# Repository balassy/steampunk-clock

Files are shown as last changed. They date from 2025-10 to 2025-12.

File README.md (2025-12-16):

# Steampunk Clock 🕰️

 

## Hardware 🪛

### Components 🔩

- Wemos D1 Mini microcontroller (ESP8266)
- PCF8574 I2C expander module 
- DS3231 RTC module + LIR2032 rechargable 3.6V battery
- 2× SG90 servo motors
- 2× yellow led filament strips 38mm length
- 2× 100 Ω resistors
- 4-position (rotary) switch
- Push button
- Active buzzer (12×9.5mm)
- Cables, connectors

### Wiring 🛠️

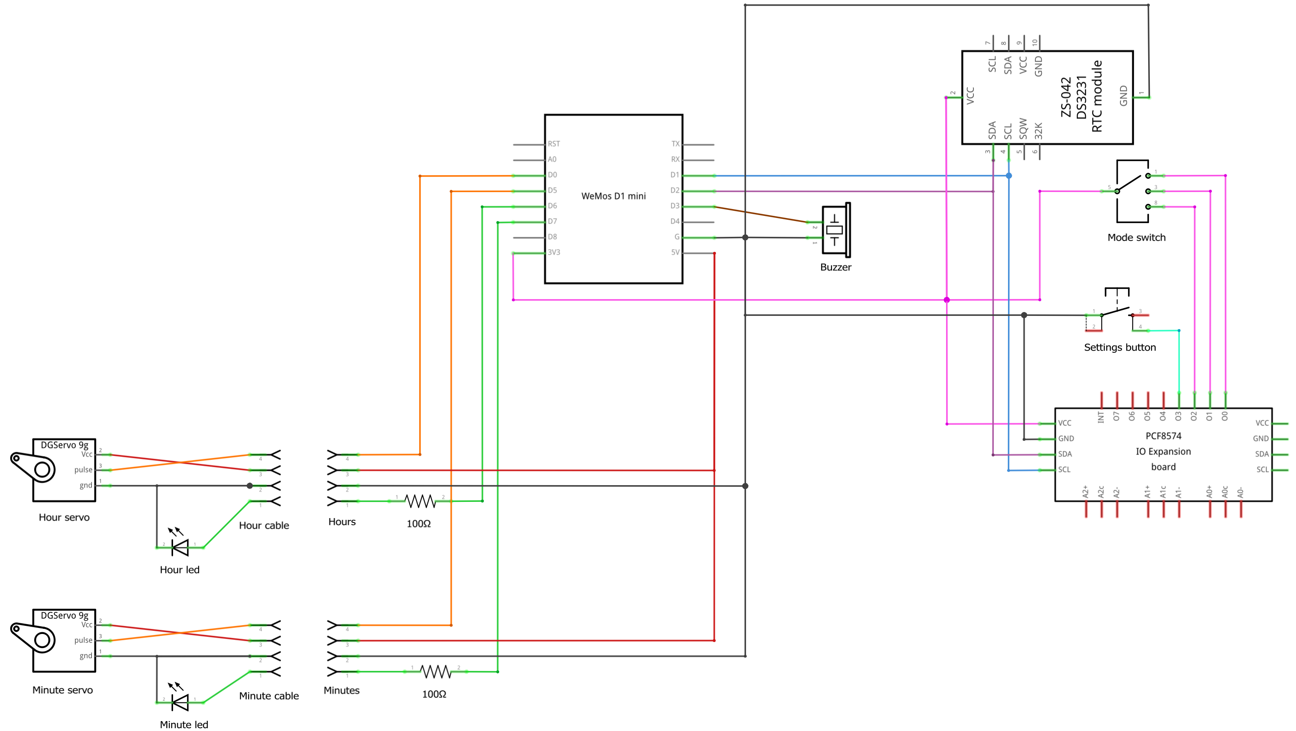
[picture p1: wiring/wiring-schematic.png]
Wiring schematic


See the details in the [wiring/steampunk-clock.fzz](./wiring/steampunk-clock.fzz) file. 

## Software 💻

### Getting Started 🚀

Install the [Arduino Maker Workshop](https://marketplace.visualstudio.com/items?itemName=TheLastOutpostWorkshop.arduino-maker-workshop) Visual Studio Code extension.

Install the following libraries:
- [Adafruit BusIO by Adafruit](https://github.com/adafruit/Adafruit_BusIO)
- [Adafruit PCF8574 by Adafruit](https://github.com/adafruit/Adafruit_PCF8574)
- [RTCLib by Adafruit](https://github.com/adafruit/RTClib)
- [WiFiManager by tzapu](https://github.com/tzapu/WiFiManager)
- [OneButton by Matthias Hertel](https://github.com/mathertel/OneButton)

The exact versions of these libraries used to create this code are visible in the [sketch.yaml](./sketch.yaml) file.

### Configuration ⚙️

Check the settings in the [config.h](./config.h) file.

**IMPORTANT FOR SECURITY!** Make sure to set a custom password in the `WIFI_AP_PASSWORD` field!

### Connecting to WiFi 📶

When the RTC module reports power loss the clock connects to a Network Time Protocol (NTP) server over the internet to get the current time.

The first time the module will create a temporary WiFi access point with the SSID and password defined in the `WIFI_AP_SSID` and `WIFI_AP_PASSWORD` values in the [config.h](./config.h) file.

Steps to connect to your local wireless network:

- Connect to this temporary access point.
- Navigate to http://192.168.4.1 in your browser.
- Select your network and enter your WiFi password.

## Acknowledgements 🙏

Thanks to Werner Rothschopf for his NTP articles:

- [NTP DST for the ESP8266](https://werner.rothschopf.net/202011_arduino_esp8266_ntp_en.htm)
- [NTP / Timezone Configuration via Webserver Interface (ESP8266, ESP32)](https://werner.rothschopf.net/202011_arduino_esp8266_ntp_en.htm)

## About the author

This project is created and maintained by [György Balássy](https://www.linkedin.com/in/balassy).

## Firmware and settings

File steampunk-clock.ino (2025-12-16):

// Platform libraries.
#include <Arduino.h>     // To add IntelliSense for platform constants.

// Third-party libraries.
#include <WiFiManager.h>      // https://github.com/tzapu/WiFiManager
#include <OneButton.h>        // https://github.com/mathertel/OneButton
#include <Adafruit_PCF8574.h> // https://github.com/adafruit/Adafruit_PCF8574
#include <Wire.h>             // I2C library

// Read configuration and secrets.
#include "config.h"

// Project classes.
#include "beep-manager.h"
#include "reboot-manager.h"
#include "ntp-manager.h"
#include "rtc-manager.h"
#include "selector-switch.h"
#include "speed-servo.h"
#include "status-led.h"

#define BUTTON_ACTIVE_LOW true

Adafruit_PCF8574 expander;
BeepManager beepManager;
NTPManager ntpManager;
SelectorSwitch selectorSwitch;
SpeedServo hourServo;
SpeedServo minuteServo;
StatusLed statusLed;
StatusLed hourLed;
StatusLed minuteLed;
RTCManager rtc;
OneButton settingsButton;

unsigned long lastClockUpdateMsec = 0;

enum Mode {
  ALL_LIGHTS_OFF = 0,
  BACKLIGHTS_ONLY,
  AMBIENT_LIGHTS_ONLY,
  ALL_LIGHTS_ON
};

void setup() {
  initSerial();
  initExpander();
  initLeds();
  initButton();
  initSwitch();
  
  if (RebootManager::isReset())
  {
    Serial.println(F("setup: Detected reset."));
  } else {
    Serial.println(F("setup: Detected power-up boot."));
  }
  RebootManager::markSetupComplete();
  
  initRTC();
  initServos();
  initBuzzer();

  Serial.println(F("setup: DONE."));
}

void loop() {
  // IMPORTANT! Do NOT use delay() in the main loop when using OneButton, as it would prevent the button from being handled!
  bool settingsButtonState = (expander.digitalRead(EXPANDER_PIN_SETTINGS_BUTTON) == LOW);
  settingsButton.tick(settingsButtonState);

  selectorSwitch.tick();

  beepManager.loop();

  // Manually detecting the number of milliseconds passed to avoid using delay() which would block button handling.
  unsigned long currentMsec = millis();
  if(currentMsec - lastClockUpdateMsec >= CLOCK_UPDATE_INTERVAL_MSEC) {
    lastClockUpdateMsec = currentMsec;
    updateClock();
  }
}

void initSerial() {
  Serial.begin(SERIAL_BAUD_RATE);
  Serial.println();
  Serial.println(F("initSerial: Initializing serial connection DONE."));
}

void initExpander() {
  Serial.println(F("initExpander: Initializing I2C expander..."));

  if (!expander.begin(0x20, &Wire)) {
    Serial.println(F("initExpander: Couldn't find PCF8574 extender board on the bus, boot halted!"));
    while (1);
  }

  Serial.println(F("initExpander: Initializing I2C expander DONE."));
}

void initLeds() {
  Serial.println(F("initLeds: Initializing LEDs..."));

  statusLed.setPin(PIN_LED, LOW, HIGH);
  
  statusLed.turnOn();
  delay(500);
  statusLed.turnOff();
  
  hourLed.setPin(PIN_HOUR_LED, HIGH, LOW);
  hourLed.turnOn();
  delay(500);
  hourLed.turnOff();

  minuteLed.setPin(PIN_MINUTE_LED, HIGH, LOW);
  minuteLed.turnOn();
  delay(500);
  minuteLed.turnOff();

  Serial.println(F("initLeds: Initializing LEDs DONE."));
}

void initBuzzer() {
  Serial.println(F("initBuzzer: Initializing buzzer..."));
  beepManager.init(PIN_BUZZER);
  Serial.println(F("initBuzzer: Initializing buzzer DONE."));
}

void initButton() {
  Serial.println(F("initButton: Initializing settings button..."));

  expander.pinMode(EXPANDER_PIN_SETTINGS_BUTTON, INPUT_PULLUP);

  settingsButton.setup(STATE_UPDATED_MANUALLY, BUTTON_ACTIVE_LOW);
  settingsButton.attachClick(onButtonClicked);
  settingsButton.attachDoubleClick(onButtonDoubleClicked);
  settingsButton.attachLongPressStop(onButtonLongClicked);

  Serial.println(F("initButton: Initializing settings button DONE."));
}

void initSwitch() {
  Serial.println(F("setup: Initializing selector switch..."));
  selectorSwitch.init(expander); 

  selectorSwitch.attachOnPositionChanged([](int position){
    Serial.print(F("Selector switch position changed to: "));
    Serial.println(position);
    onModeChanged(static_cast<Mode>(position));
  });

  Serial.println(F("setup: Initializing selector switch DONE."));
}

void initNetwork() {
  Serial.println(F("initNetwork: Initializing network..."));
  
  WiFiManager wifiManager;
  bool isConnected;
  isConnected = wifiManager.autoConnect(WIFI_AP_SSID, WIFI_AP_PASSWORD);

  if(!isConnected) {
    Serial.println("initNetwork: Failed to connect, restarting...");
    ESP.restart();
  } 
  else { 
    Serial.println("initNetwork: Connected successfully to " + String(WIFI_AP_SSID));
  }

  Serial.println(F("initNetwork: Initializing network DONE."));
}

void initNTP() {
  Serial.println(F("initNTP: Connecting to NTP server..."));
  ntpManager.init(NTP_TIMEZONE, NTP_SERVER);
  Serial.println(F("initNTP: Initializing NTP DONE."));
}

void initRTC() {
  rtc.init(PIN_RTC_SDA, PIN_RTC_SCL);

  if(rtc.isAdjustmentNeeded()) {
    Serial.println(F("initRTC: RTC adjustment is needed, setting the time."));

    initNetwork();
    initNTP();

    Serial.println(F("initRTC: Fetching current NTP time... "));
    NTPDateTime ntpTime;
    ntpManager.getCurrentTime(ntpTime);

    Serial.print(F("initRTC: NTP time is: "));
    NTPManager::printDateTime(ntpTime);

    Serial.print(F("initRTC: Setting RTC time to NTP time: "));
    DateTime initialDateTime;
    convertNtpDateTimeToRtcDateTime(ntpTime, initialDateTime);
    RTCManager::printDateTime(initialDateTime);
    rtc.setCurrentTime(initialDateTime);
  } else {
    Serial.print(F("initRTC: RTC adjustment is NOT needed, keeping the previously set time: "));
    DateTime currentRtcTime = rtc.getCurrentTime();
    RTCManager::printDateTime(currentRtcTime);
  }
  Serial.println(F("initRTC: Initializing RTC DONE."));
}

void initServos() {
  Serial.println(F("initServos: Initializing hour servo..."));
  hourLed.turnOn();
  hourServo.setPin(PIN_SERVO_HOUR);
  setHour(23);
  delay(2000);
  setHour(0);
  delay(2000);
  setHour(5);
  delay(2000);

  for (int h = 0; h < 12; h++) {
    setHour(h);
    delay(500);
  }
  hourLed.turnOff();
 
  Serial.println(F("initServos: Initializing minute servo..."));
  minuteLed.turnOn();
  minuteServo.setPin(PIN_SERVO_MINUTE);
  setMinute(59);
  delay(500);
  setMinute(30);
  delay(500); 
  setMinute(0);
  minuteLed.turnOff(); 

  Serial.println(F("initServos: Initializing servos DONE."));
}


void updateClock() {
  Serial.println(F("updateClock: Updating clock..."));

  statusLed.toggle();

  DateTime now = rtc.getCurrentTime();
  RTCManager::printDateTime(now);

  setHour(now.hour());
  setMinute(now.minute());

  Serial.println(F("updateClock: Updating clock DONE."));
}

static void onButtonClicked() {
  Serial.println("onButtonClicked: Single clicked detected!");
}

static void onButtonDoubleClicked() {
  Serial.println("onButtonDoubleClicked: Double clicked detected!");
}

static void onButtonLongClicked() {
  Serial.println("onButtonLongClicked: Long clicked detected!");
  beepManager.beep(100);
}

static void onModeChanged(Mode newMode) {
  //TODO: Fill in the implementation to change lighting based on mode.
  switch (newMode)
  {
    case ALL_LIGHTS_OFF:
      Serial.println("onModeChanged: ALL_LIGHTS_OFF selected.");
      hourLed.turnOff();
      minuteLed.turnOff();
      break;
    
    case BACKLIGHTS_ONLY:
      Serial.println("onModeChanged: BACKLIGHTS_ONLY selected.");
      hourLed.turnOn();
      minuteLed.turnOff();
      break;

    case AMBIENT_LIGHTS_ONLY:
      Serial.println("onModeChanged: AMBIENT_LIGHTS_ONLY selected.");
      hourLed.turnOff();
      minuteLed.turnOn();
      break;

    case ALL_LIGHTS_ON:
      Serial.println("onModeChanged: ALL_LIGHTS_ON selected.");
      hourLed.turnOn();
      minuteLed.turnOn();
      break;

    default:
      break;
  }
}

void setHour(int hour) {
  Serial.print(F("setHour: Setting hour to "));
  Serial.println(hour);

  hour = constrain(hour, 0, 23);

  // The full display is about 97 degree.
  // Map 0-11 hours to 41-159 degrees, inverting the direction (leftmost position is 0 hour).
  int position = map(hour % 12, 0, 11, 159, 41);
  hourServo.moveTo(position);
}

void setMinute(int minute) {
  Serial.print(F("setMinute: Setting minute to "));
  Serial.println(minute);

  minute = constrain(minute, 0, 59);

  // Map 0-59 minutes to 0-180 degrees, inverting the direction (leftmost position is 0 minute).
  int position = map(minute, 0, 59, 180, 0);
  minuteServo.moveTo(position);
}

void convertNtpDateTimeToRtcDateTime(const NTPDateTime &ntpDt, DateTime &rtcDt) {
  rtcDt = DateTime(ntpDt.year, ntpDt.month, ntpDt.day, ntpDt.hour, ntpDt.minute, ntpDt.second);
} 

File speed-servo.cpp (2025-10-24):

// Platform libraries.
#include <Arduino.h>     // To add IntelliSense for platform constants.

#include "speed-servo.h"

const int MOVE_STEP_DELAY_MSEC = 2;

void SpeedServo::setPin(uint8_t pin) {
  _servo.attach(pin, 700, 2300);

  // Give the servo a small moment to respond after attaching.
  delay(10);  
}

void SpeedServo::moveTo(int newPosition) {
  newPosition = constrain(newPosition, 0, 180);

  // Check if the servo is properly initialized.
  if (!_servo.attached()) {
    Serial.println(F("SpeedServo::moveTo: Servo cannot move, because it is not attached!"));
    return;
  }

  // Get current servo position (0-180).
  int currentPosition = _servo.read();

  Serial.println(F("SpeedServo::moveTo: Moving servo from position ") + String(currentPosition) +
                 F(" to position ") + String(newPosition));

  // Unknown current position -> write target directly
  if (currentPosition < 0 || currentPosition > 180) {
    _servo.write(newPosition);
    return;
  }

  // Do not move if already in position.
  if (currentPosition == newPosition) {
    return;
  }

  // Determine moving direction.
  int step = (newPosition > currentPosition) ? 1 : -1;

  for (int pos = currentPosition; pos != newPosition; pos += step) {
    _servo.write(pos);
    delay(MOVE_STEP_DELAY_MSEC);
  }

  // Ensure final position exactly set.
  _servo.write(newPosition);
}

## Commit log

2025-10-24 feat: servo control
2025-10-24 feat: multiple LEDs
2025-10-24 feat: getting current time from NTP with time zone proof of concept
2025-10-25 feat: get current time from NTP when RTC lost power
2025-10-25 fix: re-added missing serial print for NTP time
    [steampunk-clock.ino]
2025-10-25 feat: boot manager to detect reset and power up
    [reboot-manager.cpp, steampunk-clock.ino]
2025-10-26 feat: added button with click, double click and long click handlers
2025-10-31 feat: added selector switch
2025-10-31 fix: settings button is moved to the expander, config loaded once
    [selector-switch.cpp, steampunk-clock.ino]
2025-11-18 fix: use the correct GitHub action for Arduino CLI
2025-11-18 chore(ci): trying arduino/compile-sketches action
2025-11-18 chore(ci): fixed the fqbn by specifying the d1_mini board
2025-11-18 docs: added Arduino logo to README
2025-12-16 feat: fine tuned the hour arm positions
2025-12-16 doc: added documentation about the electronics, parts, wiring
    [steampunk-clock.fzz]
